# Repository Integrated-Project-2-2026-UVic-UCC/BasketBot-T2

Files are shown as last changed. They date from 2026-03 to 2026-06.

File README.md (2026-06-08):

# 🏀 BasketBot

**Smart Basketball Hoop — Embedded Scoring & Game System**

An ESP32-powered physical basketball scoreboard with motorized height adjustment, multi-player game modes, and a WiFi-hosted mobile web app.

---

## 📋 Overview

BasketBot combines embedded hardware (IR sensors, dual TM1637 displays, NEMA 17 stepper motor, LEDs) with a browser-based remote control interface. The ESP32 serves as both the game controller and a WiFi access point, allowing players to configure games and control the hoop from their phones.

### Key Features
- **4 Game Modes**: 1vs1, Game 21 (1–4 players), Shoot Out, and Free Practice
- **Dual IR Basket Detection**: TSOP58438 sensors detect ball passing through hoop and net with rebound filtering
- **Motorized Height Adjustment**: NEMA 17 stepper with TMC2209 driver
- **Dual Seven-Segment Displays**: TM1637-based time and score readouts
- **Mobile Web App**: Served directly by the ESP32 at `192.168.4.1`
- **Edge-Detected Scoring**: Reliable basket detection with 600 ms cooldown logic
- **Non-Blocking Homing**: Limit-switch-based calibration with automatic backoff

---

## 🎮 Game Modes

| Mode | Players | Description |
|---|---|---|
| **1vs1** | 2 | Classic head-to-head match with timer |
| **Game 21** | 1–4 | First to 21 points wins; supports up to 4 players |
| **Shoot Out** | 1-4 | Timed shooting challenge |
| **Free Practice** | Any | Practice mode with live score tracking |

---

## 🔌 Hardware Architecture

### Microcontroller
- **ESP32 DevKit** (standard development board; IO pin labels map directly to GPIO numbers)

### IR Basket Detection System (New in v2.0)
Dual TSOP58438 sensors with a 38 kHz IR LED emitter for reliable ball detection through the hoop.

| Component | GPIO | Type | Description |
|---|---|---|---|
| Upper Sensor (hoop) | 15 | INPUT | TSOP58438 — detects ball at rim level |
| Lower Sensor (net) | 13 | INPUT | TSOP58438 — detects ball passing through net |
| IR LED Emitter | 12 | PWM OUT | 940 nm IR LED driven at 38 kHz |

**Detection Logic:**
- Ball must break the upper sensor beam first, then the lower sensor within `600 ms`
- Rebounds (upper sensor only) are filtered out with a timeout
- Shots from below the hoop are ignored
- 600 ms cooldown prevents double-counting

### Displays
| Display | Purpose | CLK | DIO |
|---|---|-----|-----|
| TM1637 #1 | Timer | GPIO 26 | GPIO 4 |
| TM1637 #2 | Score | GPIO 14 | GPIO 27 |

### Motor System
| Component | Pin | Notes |
|---|-----|---|
| TMC2209 STEP | GPIO 32 | Step pulses |
| TMC2209 DIR | GPIO 33 | Direction |
| TMC2209 EN | GPIO 25 | Active LOW |
| Limit Switch | GPIO 35 | INPUT_PULLUP |

&gt; **Note:** GPIO 36 was avoided because it lacks internal pull-up on ESP32. GPIO 34/35 are input-only on some boards.

### Game Buttons & LEDs
| Component | GPIO | Mode | Notes |
|---|---|---|---|
| Button Team A | 16 | INPUT_PULLUP | Confirm basket (1vs1) |
| Button Team B | 17 | INPUT_PULLUP | Confirm basket (1vs1) |
| Button Ready | 16 | INPUT_PULLUP | Shared with Team A button |
| Green LED | 21 | OUTPUT | Basket pending / status |
| Blue LED | 19 | OUTPUT | Team A scored |
| Red LED | 18 | OUTPUT | Team B scored |

### Power Supply
- **12V 5A** supply recommended for stability
- **LM2596** buck converter steps 12V → 5V for ESP32 **VIN** pin
- **Never connect 5V to the 3.3V pin**

---

## 📡 Web App

The ESP32 creates a WiFi access point:

- **SSID**: `BasketBot`
- **IP Address**: `192.168.4.1`

### Features
- 4-mode grid layout for game selection
- Drum-style pickers for player count and settings
- Motor setup card with slider and quick-select height buttons
- Mobile-first responsive design

---

## 🗂️ Project Structure

### Naming Convention
All game logic files use mode-specific prefixes to avoid naming conflicts in the global Arduino scope:
- `_g1_` → 1vs1
- `_g21_` → Game 21
- `_gp_` / `_so_` / `_mc_` → Other modes

---

## 🔧 Installation & Setup

### Prerequisites
- Arduino IDE with ESP32 board support
- [TM1637Display](https://github.com/avishorp/TM1637) library by Avishay Orpaz (via Library Manager)

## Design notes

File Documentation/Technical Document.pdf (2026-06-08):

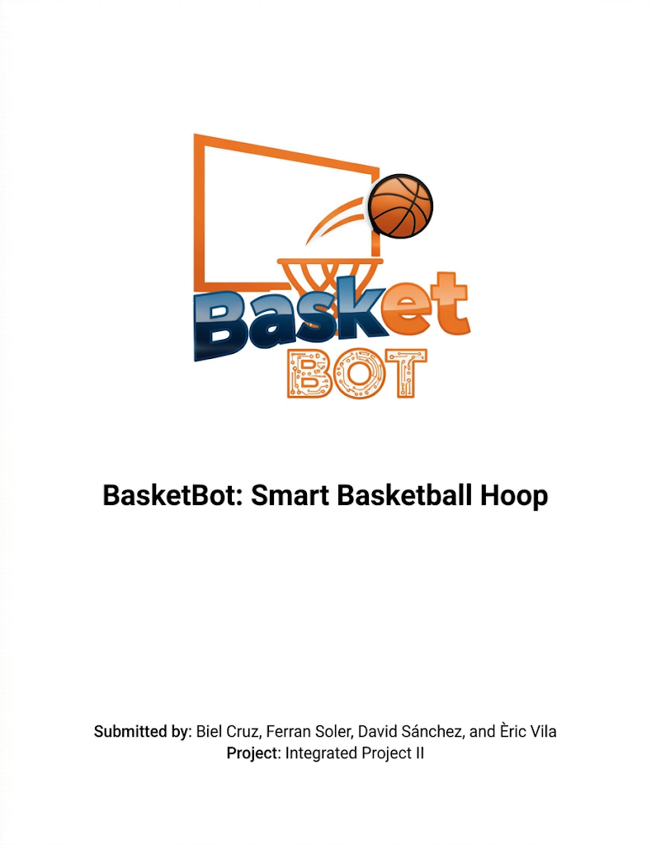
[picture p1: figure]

## Summary

BasketBot is a smart basketball hoop designed to automate score tracking, time control, and turn management in informal games. The primary objective of this mechatronic system is to resolve typical on-court disputes, allowing players to focus exclusively on the game. To achieve this, the project integrates embedded hardware, electronic scoreboards, and a web control interface.

At the hardware level, the hoop features an automated lifting mechanism driven by a NEMA 17 stepper motor with an integrated lead screw, which allows the height of the structure to be adjusted remotely for different types of players. The core of the system is an ESP32 microcontroller that acts as a local Wi-Fi access point and manages peripheral devices. This includes a TMC2209 driver for smooth motor control, a dual infrared sensor (TSOP58438 receivers) for precise and interference-free ball detection, and TM1637 displays alongside LED indicators for instantaneous visual feedback.

The software has been designed to operate asynchronously, ensuring that basket detection and motor movement do not interrupt network communication. Through the locally hosted web application, users can select from four different game modes: Free Practice, The 21, 1 vs 1, and Shootout. During functional testing, communication between the board and the web app demonstrated unnoticeable latency, and the detection accuracy reached 87%, while also overcoming initial mechanical obstacles by stabilizing the lifting structure.

## Table of Contents

## 1. Introduction / State of the art – Benchmarking

Basketball is a global sport, played at both professional and recreational levels. In informal settings—such as schoolyards, parks, or sports centers—matches are typically self-managed by the players themselves. This lack of an external refereeing figure delegates the tasks of tracking the score, managing possession turns, and enforcing the rules of the game to the participants.

The dynamic nature of the game often leads to confusion, involuntary errors, or, occasionally, dishonest behavior that diminishes the sporting experience. The primary motivation of this project is the creation of a smart basketball hoop capable of automating score recording, turn management, and timing.

The idea wasn't born in a lab, but on the court itself. Anyone who has ever played a pickup game with friends knows the drill: you’re winning, the game gets intense, and suddenly, nobody can agree on the score. "Was it 10–8 or 11–9?" That minor doubt sparks arguments and breaks the rhythm of the game.

We are building this project because we want players to forget about the numbers and focus on the ball. We want to use technology to resolve those conflicts and keep the game as clean and fluid as possible. Ultimately, the goal is for the hoop to work for us, not the other way around.

## 2. Objectives

Following the baseline criteria established in the initial project milestones, this system bridges the gap between digital score-tracking web frameworks and automated physical machinery to solve the disputes and tracking errors typical of self-managed, informal basketball games. The main objective of this project is to design, program, and build "BasketBot"—a fully functional, self-contained smart basketball hoop system that integrates embedded hardware and electronic scoreboards with a local WiFi web application to manage games, scoring, timing, and automated mechanical height positioning. Operated by an ESP32 microcontroller acting as a local Access Point, the system coordinates multi-display time and scoreboards alongside a responsive mobile interface to select interactive game modes and dynamically configure match parameters.

To achieve this, the specific objectives focus on delivering robust mechatronic automation, high-integrity electronics, and reliable software logic. The system implements automated mechanical height positioning spanning a linear travel, driven by a NEMA 17 stepper motor and regulated via a physical microswitch homing sequence. On the data layer, precise score registration is guaranteed by utilizing a specialized edge-detection algorithm (HIGH-to-LOW transition logic) with strict software cooldown timers to eliminate multi-count sensor ghosting. Power distribution is optimized using an LM2596 DC-DC buck converter to step down a stable 12V main source into a clean 5V line connected directly to the ESP32 VIN pin, protecting sensitive digital control logic from inductive motor loads. Finally, the entire modular software architecture and interactive game routines are structured, version-controlled, and documented collaboratively using a Git repository on GitHub.

## 3. Development of the project

In order to achieve the final prototype and fulfill all the proposed objectives, it is essential to divide the project development into several core areas. On one hand, we find the tasks focused on mechanical design, such as numerical calculations, 3D modeling, and lifting mechanisms. On the other hand, the project focuses on the electronic and control systems, which encompass the electrical schematics, sensor integration, and mobile app connectivity. Finally, all aspects regarding software programming and system firmware are thoroughly developed.

## 3.1. Analysis of the problem and possible solutions

To achieve a variable-height basketball hoop that syncs data with a mobile application, several architectural solutions were considered:

- Mechanical Lifting Mechanism: We evaluated several options for the basket-lifting system, including a gear-based mechanism. But in the end, for the sake of simplicity and control, we opted for a motorized lever mechanism driven by a stepper motor.

In this system, the motor drives a rigid rod connected directly to the backboard mount. This creates an inverted lever system: when the motor pushes the rod upward, the basketball hoop moves downward, and vice versa.

- Electronic Score Tracking: We analyzed using ultrasonic sensors, infrared (IR) break-beam sensors, or a camera system to detect when a basket is scored. IR/Ultrasonic sensors were selected due to their reliability and low computational requirements.
- Connectivity: Wi-Fi in Access Point (AP) mode was chosen to facilitate direct, low-latency communication with the web application hosted on the ESP32. By establishing its own local network, the microcontroller allows users to access the control interface directly via a web browser using its local IP address, completely eliminating the need for an external network or internet connection.

## 3.2. Description of the design

The BasketBot is a mechatronic system defined by the following core characteristics:

- Dimensions & Weight: 65 cm long by 35 cm wide. Weighing 6 kg.
- Degrees of Freedom: One vertical degree of freedom (translation for height adjustment).
- Power Supply: The system is powered from a single external 12V DC power supply. A DC-DC step-down regulator (LM2596) converts this voltage to 5V, which powers the two TM1637 displays (scoreboard and timer). The remaining components — ESP32, TSOP4838, ultra sonics sensor, LEDs, push buttons, and limit switches — operate at 3.3V, supplied by the ESP32’s internal regulator. The TMC2209 driver and the NEMA 17 motor are powered directly from the 12V input. The 330Ω and 220Ω resistors limit the current of the LEDs, protecting them.
- Microcontroller & Language: The system is controlled by an ESP32 microcontroller, programmed in Arduino using the Arduino IDE.

## 3.2.1. Mechanical design

The mechanical design of the system was conceived to fulfil two main objectives: to provide a rigid and robust structure capable of withstanding impacts and movements, and to implement a reliable vertical lifting mechanism. The design is clearly divided into fixed structural components and mobile structural components.

Fixed Structural Components

Rim:
It is a simple design, engineered with enough strength to withstand ball impacts corresponding to its size, yet retaining the flexibility that characterizes a basketball hoop rim. It also features four holes on the back section to ensure it can be easily and securely attached to the backboard.

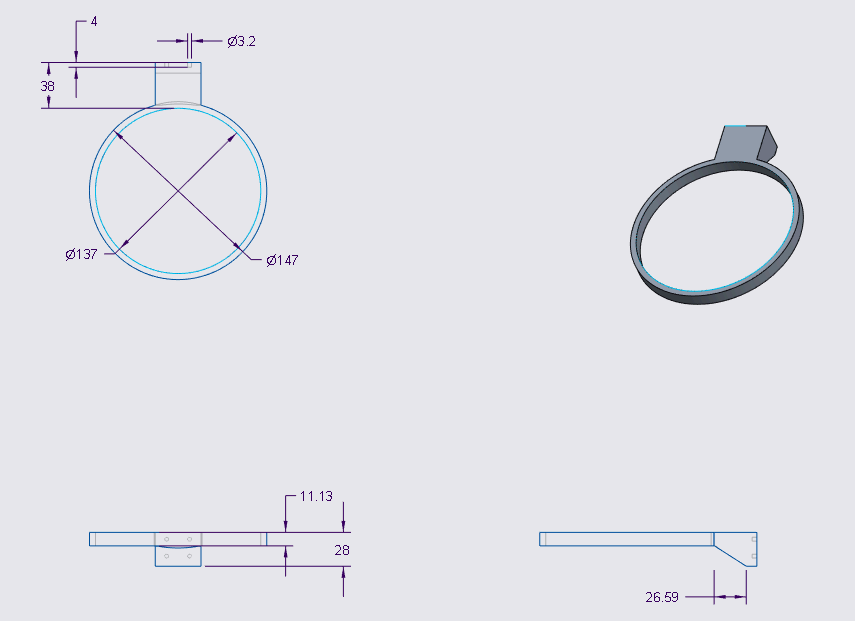
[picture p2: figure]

Figure 1 Rim

Main Structure:
The main body of the structure is constructed from wood, which provides a solid and stable frame for the system. To achieve the exact required height, a custom plastic base was integrated at the bottom for precise adjustment. Additionally, the assembly includes a counterweight system designed to balance the structure's weight, ensuring that the basket remains stable and does not tilt or fall forward during operation.

Mobile Structural Components

Support Arms and Sliding Carriages:
The mechanism that moves and supports the board operates like a dual-arm parallel system. It consists of two pairs of parts stacked one above the other. This gives the board four points of support at all times, preventing it from swaying or tilting forward as it rises and falls.

On one side, we have the support arms, which are two identical pieces attached to the back of the panel. On the other side, these arms connect to the following square pieces. These are hollow pieces that are fixed to the basket body. One of them has a pin or joint on the back connected directly to the driveshaft. In this way, it receives the force from the engine directly and pulls the entire assembly.

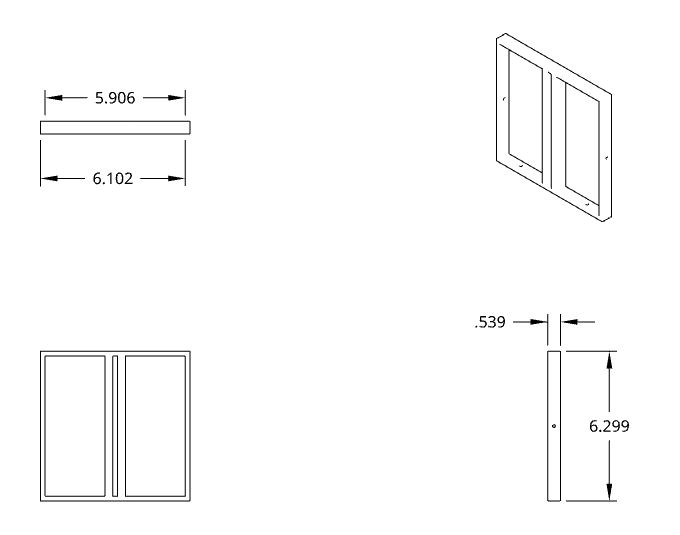
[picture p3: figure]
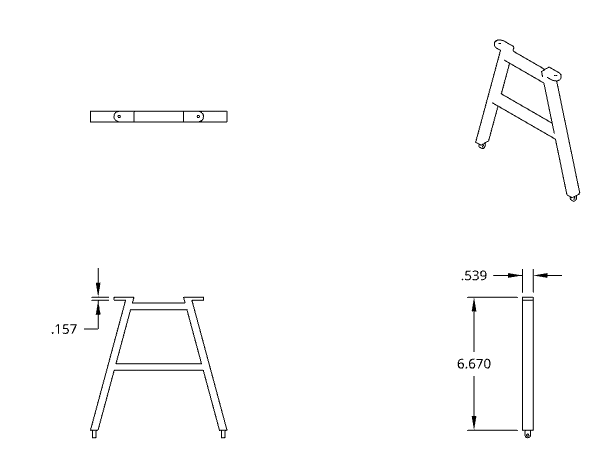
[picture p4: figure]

Figure 2 Support Arms and Sliding Carriages

Brackets / Connectors:
This small component was designed to enable the articulated connection between the backboard and the supports of the mechanism that drives the movement. It has a solid base with two holes for a secure and sturdy collar, and a double upper support with an axle that allows the lifting system to rotate and articulate smoothly and stably.

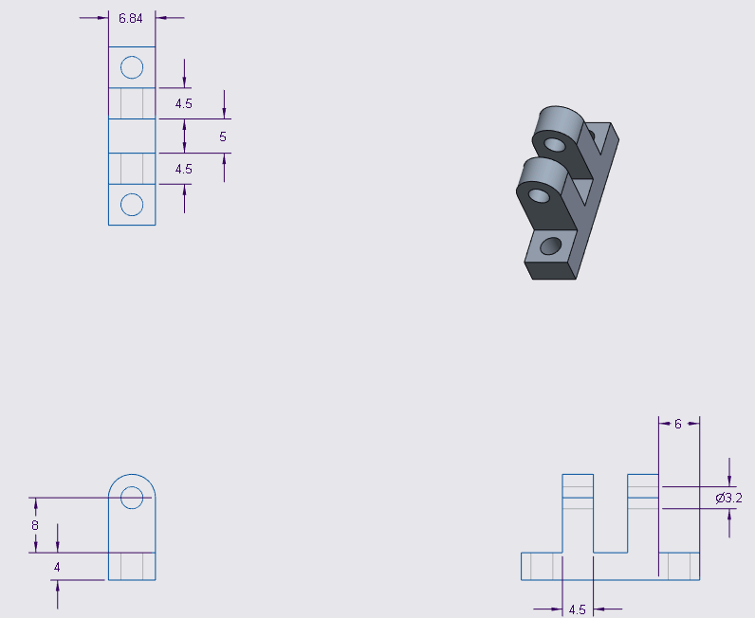
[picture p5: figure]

Figure 3 Brackets

Transmission Rod (Linkage / Connecting Rod):
It is the direct transmission between the stepper motor and the basket's moving structure. Its function is to convert the motor's motion into a vertical linear force that pushes the board support up or down, thereby generating the basket's regulated displacement.

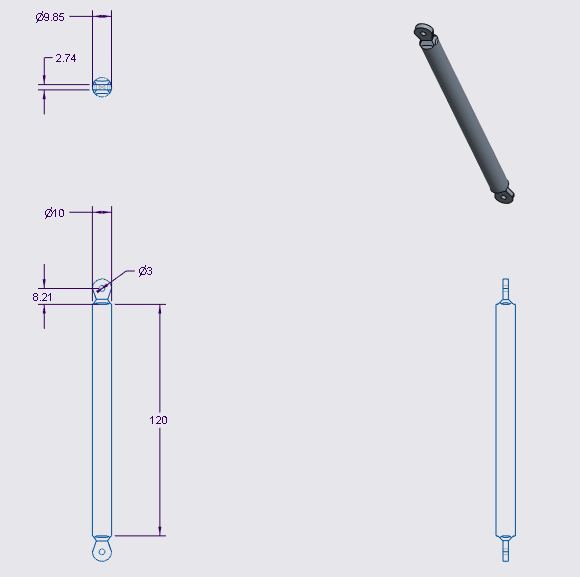
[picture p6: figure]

Figure 4 Transmission Rod

## 3.2.2. Electrical design

Connection Mapping and Pin Assignment

For the final assembly, we organized the ESP32 connections in a much more efficient manner (Table 1). Compared to the first version of the prototype, we had to reassign the pins of some components (such as the displays).

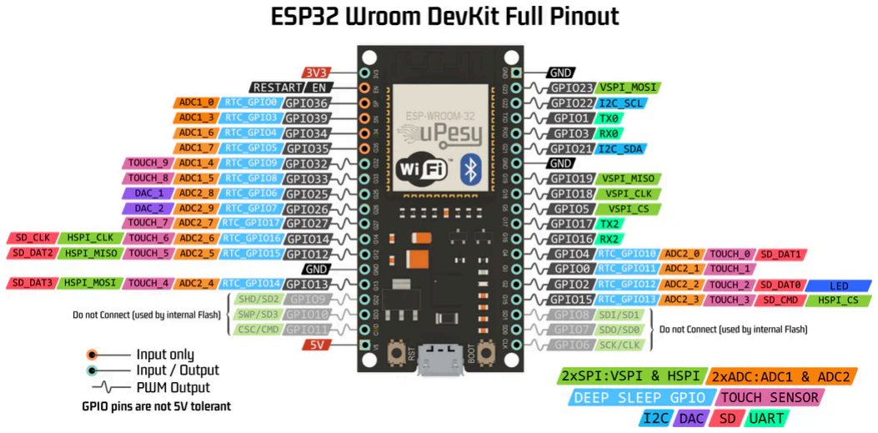
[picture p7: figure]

Figure 5 ESP32 Pinout

IR Basket Sensors
- TOP Sensor (TSOP58438): GPIO 15.
- BOTTOM Sensor (TSOP58438): GPIO 13.
- IR Emitter LED (38kHz): GPIO 12.

Displays (TM1637)
- Display Timer CLK: GPIO 26.
- Display Timer DIO: GPIO 4.
- Display Score CLK: GPIO 14.
- Display Score DIO: GPIO 27.

Basket Motor (NEMA 17)
- STEP: GPIO 32.
- DIR: GPIO 33.
- ENABLE: GPIO 25.
- Limit Switch: GPIO 35

Buttons and LEDs (Games)
- Team A Button / Ready Button: GPIO 16.
- Team B Button: GPIO 17.
- Green LED (Pending basket / Indicator): GPIO 21.
- Blue LED (Team A scored): GPIO 19.
- Red LED (Team B scored): GPIO 18.

Control Architecture (The “Brain”)

The core of the BasketBot electrical subsystem is governed by a central control unit based on the ESP32 Wroom DevKit microcontroller. This device acts as the "brain" of the smart basketball hoop, serving as the central node where data acquisition lines (sensors), game logic algorithms, mechanical actuation systems (motor), and the user interface (LEDs and web application) converge.

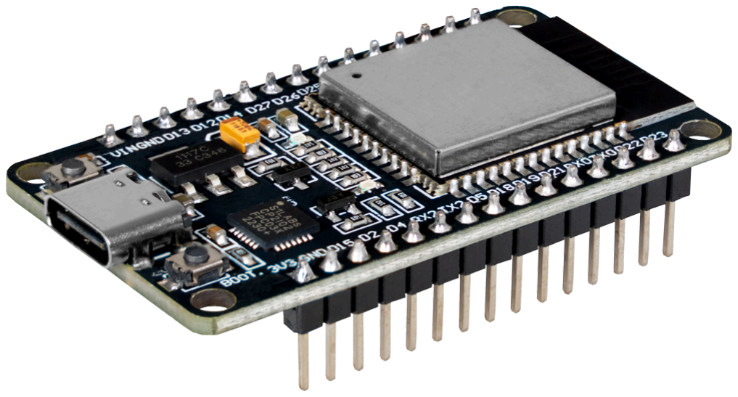
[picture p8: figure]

Figure 6 ESP32

The selection of the ESP32 instead of other market alternatives (such as 8-bit Arduino platforms) is based on the project's technical and connectivity requirements:

- Integrated Connectivity: The ESP32 incorporates certified hardware modules for Wi-Fi and Bluetooth (BR/EDR and BLE). This feature is essential to achieve the goal of connecting the basketball hoop to a web-based mobile application, eliminating the need for external communication chips that would increase both the cost and complexity of the electrical design.
- High Peripheral Density and PWM Channels: The chip provides a wide array of addressable GPIO pins, including internal timers, pulse generators (essential for the stepper motor driver), and serial communication ports.

Motor NEMA 17 stepper motor with integrated T8 lead screw

The selected motor is a NEMA 17 stepper motor with a 310 mm T8 lead screw integrated directly into the shaft. Its main electrical and mechanical characteristics are as follows:

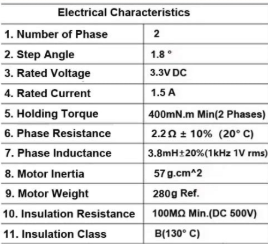
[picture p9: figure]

Table 1 Electrical Characteristics

In order to meet the functional requirements, several technological alternatives were evaluated before making the final decision. The main selection criteria were: the ability to perform open-loop position control, meaning that it does not require an external encoder to determine its position; compatibility with the ESP32; and a cost that fits within the project's budget.

Sufficient torque to move the basket structure was also a critical factor. According to the manufacturer's datasheet, the chosen stepper motor is capable of lifting a maximum load of 12 kg. During the design phase, the total weight of our basket prototype was calculated to be approximately 6 kg. This means the motor offers twice the capacity required by the system, providing an ample safety margin to handle the structure effortlessly, prevent any loss of steps, and overcome unexpected friction during movement.

The main objective of this subsystem is to enable the motorized adjustment of the basketball hoop's height, allowing the BasketBot system to adapt to different types of players—whether children, teenagers, or adults—without requiring manual intervention.

The height adjustment is carried out through a lead screw mechanism driven by a stepper motor, which converts the motor's rotational motion into a vertical linear displacement of the structure supporting the basketball hoop.

The control of this subsystem is integrated directly with the project's mobile application. Through the app, the user can select the desired hoop height before starting a game or adjust it in real time using the up and down buttons. This command is transmitted via Wi-Fi to the ESP32, which is responsible for generating the control signals required to drive the motor in the appropriate direction and reach the target position.

In addition, the subsystem incorporates two limit switches that physically define the maximum travel range of the mechanism, ensuring that the motor does not exceed the structural limits of the minimum and maximum permitted heights. This provides both system safety and protection for the mechanical components.

Driver: TMC2209

To control the NEMA 17 from the ESP32, a TMC2209 driver is used. This next-generation integrated circuit is specifically designed for bipolar stepper motors. It represents a significant improvement over more basic drivers such as the A4988, particularly in terms of quieter operation, smoother motion, and advanced functionality.

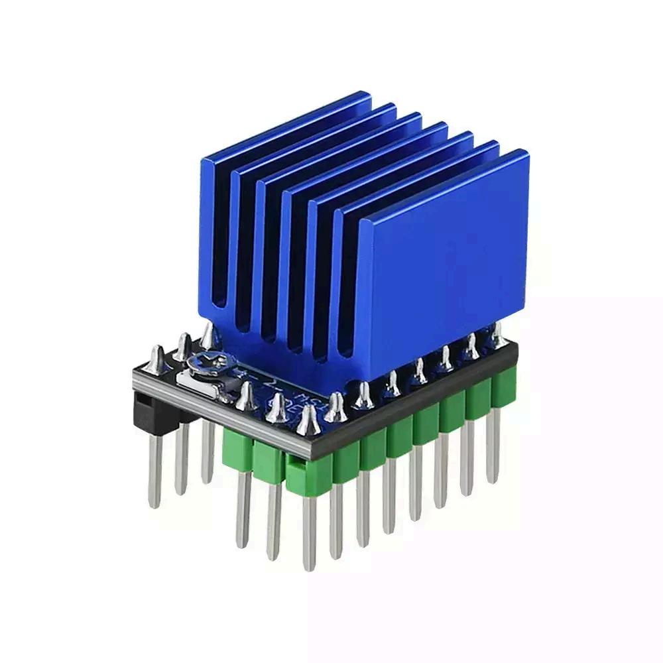
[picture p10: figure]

Figure 7 Driver TMC2209

Basic Operation of the Motor and Driver

The NEMA 17 is a bipolar stepper motor with two independent coils (Phase A and Phase B). The TMC2209 driver energizes these coils in a specific sequence, generating a rotating magnetic field that drives the rotor in precise, discrete steps with virtually silent operation.

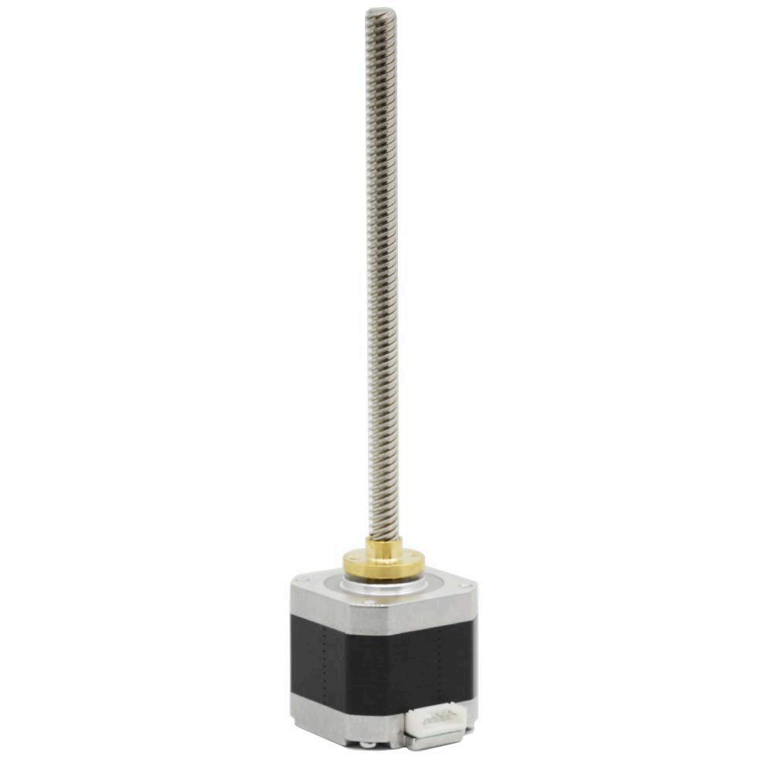
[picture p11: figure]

Figure 8 Nema 17

Each time the ESP32 sends a rising edge to GPIO 32 (STEP pin), the TMC2209 advances the motor exactly 1.8°. The direction of rotation is determined by the logic level of GPIO 33 (DIR pin).

The TMC2209 driver internally manages the coil energizing sequence and current control, so the ESP32 only needs to generate two simple digital signals, without any additional motor control computations.

Digital Scoreboards (TM1637 Displays)

The BasketBot uses two 4-digit, 7-segment display modules controlled by the TM1637 chip (one for time and another for score).

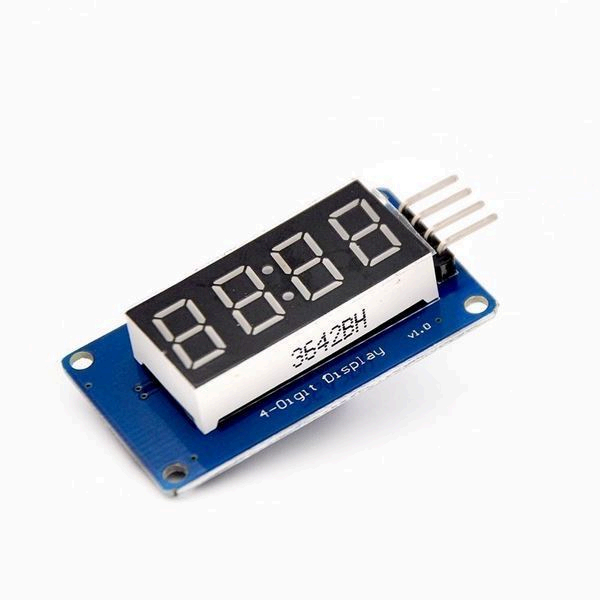
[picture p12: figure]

Figure 9 TM1637

Its selection is justified by two key electrical reasons:

- Massive pin saving: Controlling a standard 4-digit display would require 12 wires connected to the ESP32. With two displays, this would amount to 24 GPIO pins, leaving insufficient connections for the rest of the system components. The TM1637 chip acts as an intelligent intermediary and only requires 2 data wires (CLK and DIO) per display, greatly saving space on the board.
- Multiplexing (optical illusion): The TM1637 does not power all digits simultaneously, as this would consume too much energy. Instead, it turns each digit on and off sequentially at an extremely high frequency (in the kHz range). Because this switching happens so quickly, the human eye does not perceive the flickering and instead sees all four digits lit at the same time, without overloading the system.

Display Connections

Since we are using two independent displays, each one requires a two-wire connection to receive data from the ESP32.

- Time Display (Timer): The clock line (CLK) is connected to GPIO 26, and the data to GPIO 4.
- Score Display: It remains connected as before, with CLK on GPIO 14 and DIO on GPIO 27.

Feedback Indicators (RGB / Simple LEDs)

As a complement to the numeric score displays, a lighting system based on three visual indicators has been designed. These serve as a visual communication interface (Green LED, Blue LED, and Red LED).

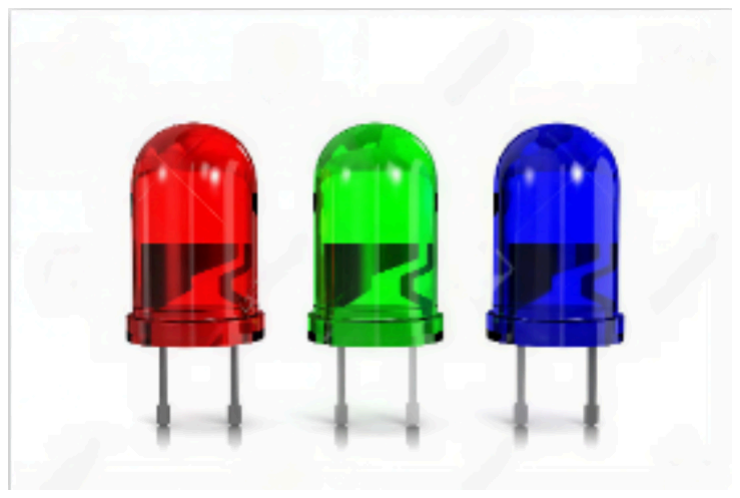
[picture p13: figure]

Figure 10 LED

Their electrical configuration and activation logic correspond to the following stages of game interaction:

Green LED: At the exact moment the ball passes through the hoop successfully, the ESP32 toggles the pin connected to this LED, producing an instant green light that confirms a valid basket.

Team Assignment LEDs (Blue and Red): These are used to identify which of the two competing teams has scored points on the scoreboard. To prevent incorrect assignments, the software requires a prior validation step:

- Physical Interface: The system includes two manual push buttons (one for the blue team and one for the red team). Electrically, these buttons are configured as digital inputs with pull-up resistors to ensure clean and stable readings.
- Digital Interface: Alternatively, the assignment can be performed remotely through the web mobile application using the same control protocol.

LEDs: Each color is assigned its own digital output channel on the ESP32. The Green LED is connected to GPIO 21; the Blue LED (which confirms a point for Team A) is connected to GPIO 19; and the Red LED (which confirms a point for Team B) is connected to GPIO 18. Each wire includes a small series resistor to prevent excessive current from reaching the LED, which could otherwise damage either the LED itself or the microcontroller pin.

Buttons (Physical Push Buttons): Physically, we have two buttons, which helps us save components and board space. They work as follows:

- 1vs1 Game mode: The Team A button is connected to GPIO 16 and the Team B button to GPIO 17. They are used to confirm which team made the basket that has just been scored.
- Mode 21, Shootout and Free modes: Not used.

Interconnection and Integration with Sensors

The system responsible for automatically and reliably detecting baskets uses a dual infrared (IR) optical barrier. The TSOP58438 receiver was selected to avoid false positives caused by sunlight or artificial lighting, as it completely ignores surrounding ambient light and only responds to infrared bursts modulated precisely at 38 kHz.

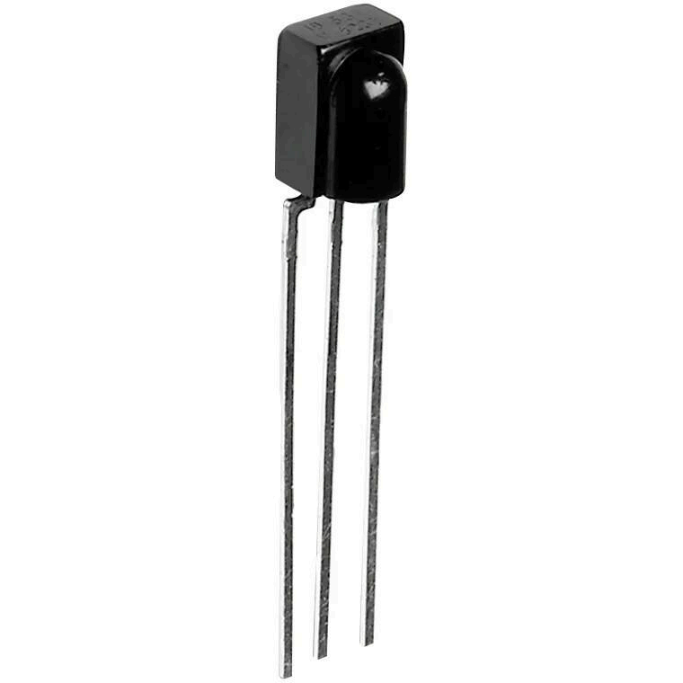
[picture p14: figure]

Figure 11 TSOP58438

To ensure a stable electrical integration free from false detections, the pin-to-pin connection between the receiver and the control architecture has been designed as follows:

- IR LED: Connected to GPIO 12; it is the LED that emits the infrared light.
- TOP Sensor: Connected to GPIO 15. It acts as an input to notify the program at the exact moment the ball begins to enter the hoop.
- BOTTOM Sensor: Connected to GPIO 13. It acts as a second input to confirm that the ball has fully passed through and fallen completely.

## 3.2.3. Control and software

Game and Team Validation Flow Logic

To prevent errors or false scoring, a state machine has been implemented under a strict dual-condition flow:

1. Detection Phase (Physical): When the ball passes through the hoop, the IR sensors are activated. The ESP32 immediately turns on the Green LED to confirm that a valid basket has been physically detected. At this stage, no points are added to the scoreboard yet.
2. Validation Phase (Human): The system then waits for a few seconds. In order for the point to be registered, the scoring team must be indicated. This is done using the manual push buttons (one for the Blue team and one for the Red team) or directly through the web application.
3. Update Phase: Once the team signal is received (via button or Wi-Fi), the ESP32 turns off the Green LED, turns on the corresponding team LED (Blue or Red) as a visual confirmation, and automatically updates the Score Display (TM1637), adding the points to the appropriate team’s score.

Game Modes

Free (Free Practice)

This module is a free training mode with no time or scoring limits, controlled by a single scoreboard.

Objective and operation:

- Scoring: Each valid basket detected by the sensor adds +2 points.
- Visual effect: When a basket is scored, a LED (GPIO 21) lights up for 200 ms. The function turns it off in the background without using blocking code.

Web Interaction

- Manual control: The user can add +2 points or use the “Undo” button to subtract 2 points in case of an error.
- Safety: The code uses max(0, _gl_puntos - 2) to prevent the score from going below zero.
- Synchronization: Data is sent in JSON format to update the mobile screen in real time.

Win Condition

There is no win condition. The game continues accumulating points until the user presses reset or stops it from the web interface.

The 21

This mode allows 1 to 4 players to play in an automated way. It controls an indicator LED to mark the shooting time and communicates with the web interface.

Objective and scoring

The objective is to reach exactly 21 points. The game operates using a turn-based system based on a time window:

- Normal Shot: If the player scores, they earn +2 points and receive an extra “Free Throw” attempt. If they miss or time runs out, the turn passes to the next player.
- Free Throw: If the player scores, they earn +1 point and can continue taking free throws. If they miss, they lose their turn.

If the ball hits the rim and bounces out, the system immediately detects it as a miss and switches turns without waiting for the time to expire.

Win condition and penalty

- Victory: The first player to reach exactly 21 points wins.
- Penalty: If a player exceeds 21 points (for example, having 20 points and scoring 2), their score is automatically reduced to 11 points and they immediately lose their turn.

The 1 vs 1

This module manages a real-time match between two teams sharing the same hoop, using physical buttons to assign points. It uses GPIO 16 (Team A), GPIO 17 (Team B), and three control LEDs: Green (GPIO 21), Blue (GPIO 19), and Red (GPIO 18).

Objective and operation

- Objective: To score more points than the opponent before the game time runs out.
- Validation window: When a basket is scored, the Green LED turns on and a waiting state is activated. The first team to press their button within the time limit earns +2 points. If no button is pressed, the basket is cancelled.

End of match

When the timer reaches zero, the function turns off all LEDs, locks the game, determines the winner (or a draw), and sends the final result to the web interface.

Shootout

This module manages a timed competitive turn-based mode (1 to 4 players). It uses a “Ready” button (GPIO 16) and an indicator LED (GPIO 21).

Objective and operation

- Objective: Score as many baskets as possible within a time limit (e.g., 30 seconds). Each successful shot adds +1 point.
- Asynchronous timing window: If the game is paused from the web interface, the code calculates the time spent paused and compensates for it by adding it back to the board’s timer, ensuring the player does not lose any seconds.

Win condition and tiebreaker

- Victory: The player with the highest score wins.
- Automatic tiebreaker: If there is a tie for first place, an exclusive group is created where only the tied players compete. Their scores are reset to 0 for an additional round. This process is repeated until a single winner is determined.

Motor Control

To ensure everything works correctly and without freezing, the programming has been structured as a state machine that runs asynchronously (non-blocking). This is essential so that the ESP32 doesn't get "frozen" while the motor is moving; it allows the microcontroller to continue performing other tasks simultaneously, such as updating the scoreboard or managing communications. Instead of making long, single-shot movements, the code uses a function called motor_tick() that runs continuously in the program's main loop. Every time this function is called, the ESP32 checks the current state of the system and, if necessary, moves the motor a single step before continuing with the rest of the code.

The main states managing this logic are the following:

- Idle (MC_IDLE): The motor has reached its destination and remains stopped, waiting for a new height command.
- Homing (MC_HOMING_DOWN and MC_HOMING_UP): These are the two phases to find the zero point using the limit switch. First, the motor moves down until it triggers the limit switch, and then it moves up a few steps to release it, establishing this position as the reference origin.
- Moving (MC_MOVING): The active state where the motor moves (upwards or downwards) to the height in centimeters requested by the user. To do this, the system converts the desired height into a number of motor steps by applying a conversion factor of 2,000 steps per centimeter, derived from the pitch of the T8 lead screw and the motor's step angle.
- Error (MC_ERROR): The failure state the system enters when a critical anomaly is detected. In this case, the motor is immediately disabled to protect the mechanical structure.

Finally, essential safety measures have been included within the code itself to protect the mechanical structure. On one hand, if the motor moves down during the initial homing phase without finding the limit switch, the system assumes a fault has occurred, stops immediately, and enters the MC_ERROR state, disconnecting the motor to prevent any damage. On the other hand, if the motor is moving normally and unexpectedly hits the limit switch, the software instantly cancels the movement and resets the position to zero to avoid mechanical collisions.

Hoop Sensors

Phase 1: Testing and calibration program

Before integrating the sensors with the web interface or the motors, we created a simple standalone program solely to test how the IR receivers responded. This code continuously monitored the pins and displayed a message on the computer screen every time the ball passed through. Thanks to this test program, we were able to calibrate the infrared light distance and verify that the 38 kHz modulation of the emitting LED worked even under ambient light conditions.

Phase 2: Final Code

The final code was designed around three technical pillars:

Asynchronous operation: Instead of using typical delays, the code calculates real elapsed time using the ESP32’s internal clock. This is essential so the sensor can monitor the ball in the background while, at the same time, the hoop motor is moving or the user is interacting with the web application.

IR burst logic: The LED is not kept continuously on. The program activates the emitter in bursts, turns the LED off, and at that precise moment performs the digital reading. It then leaves a recovery margin before the next cycle.

State machine flow control: The program manages the ball trajectory sequentially to avoid scoring errors:

- Waiting: It waits for the upper sensor to be triggered. When this happens, it records the time and opens a safety window.
- Checking: If the lower sensor is triggered within 600 ms, the basket is validated. If the time limit is exceeded, the code assumes the ball has bounced out and returns to the initial state without scoring.
- Anti-bounce: Once a basket is detected, the system locks for 1 second. During this period, sensors are ignored to prevent rim vibrations from generating extra points.

### Displays

Score

Depending on the game mode, the score display behaves differently:

- 1vs1 mode: The display is split into two halves of 2 digits each. The left side shows Team A’s score and the right side shows Team B’s score (up to 99). The middle segments are disabled to simulate two independent scoreboards.
- 21, Shootout and Free modes: The display acts as a single 4-digit counter (0000–9999), showing the total score or the score of the active player’s turn.

Whenever a match is paused, has ended, or the system is in standby, the display shows four fast dashes (----) to visually indicate that the counter is inactive.

Timer

The same applies to the timer display:

- 1vs1 mode: Displays the total game time in minutes and seconds (MM:SS). To achieve this, the code calculates the quotient and remainder of the remaining time.
- Shootout and 21 modes: Since these are fast countdown-based shooting modes, the display is configured in integer seconds (SS), using leading zero padding for proper visual alignment.
- Free mode: Since this mode has no time restriction, the timer is disabled.
- Inactive state: As with the scoring module, if the game is paused, finished, or in standby, it shows four fast dashes (----) as a visual indicator that the game is frozen.

Web Application and Wi-Fi Communication
This subsystem interconnects the mobile web application with the ESP32 control logic through an asynchronous architecture, ensuring an instantaneous response (low latency) and completely independent operation from the internet or external network infrastructures.
- Access Point Mode: The ESP32 generates its own local Wi-Fi network with a dedicated SSID. Users connect directly to this network and access the control interface by entering the microcontroller's local IP address into any mobile web browser, eliminating the need for external routers or servers.
- Control Interface & Features: The web application features a responsive design optimized for smartphones. Through this graphical interface, users can select from the four available game modes (Free Practice, The 21, 1 vs 1, and Shootout), adjust the hoop's mechanical height in real-time, and manage the scoreboard with specialized correction features such as the Undo button.
- Asynchronous Data Flow (JSON): Data exchange between the control board and the mobile interface is handled via structured JSON payloads. By implementing non-blocking asynchronous programming based on the ESP32's internal clock (avoiding blocking code like delay()), the mobile screen updates instantaneously whenever a basket is registered or a timer changes, without ever interrupting background sensor polling or stepper motor movements.

## 3.3. Functional testing of the prototype

To validate the performance of the BasketBot, a series of experimental tests were conducted:

1. Height Adjustment Test: Initially, although the motor had sufficient torque according to its datasheet and responded perfectly to commands, the mechanism failed to lift. We discovered the issue was a lack of structural stability: the weight of the hoop tilted the motor's support shaft, preventing movement since the system requires perfect vertical alignment to avoid jamming. To solve this, we added a counterweight to balance the load and reinforcing bars to keep the structure completely upright. Thanks to these modifications, the lifting mechanism now functions perfectly, smoothly, and stably.
2. Score Detection Accuracy: 100 shots were taken to evaluate the detection system's accuracy, obtaining 87 correct detections (87%). During testing, it was found that the upper sensor required readjustment to improve detection, so it was temporarily disabled until the final version.

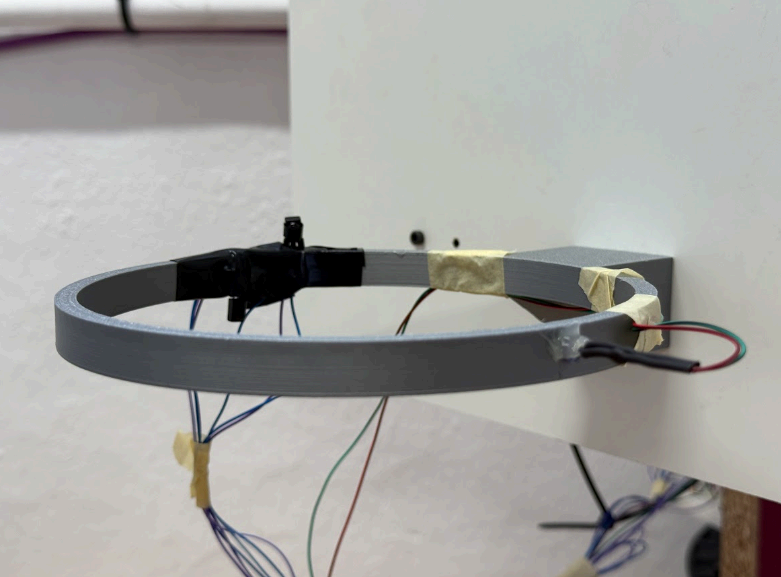
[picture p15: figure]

Figure 12 Score Detection

### 3. App Synchronization and Latency: The synchronization between the mobile

application and the physical system was highly successful and operated without any major complications. Across all available features and game modes, the application detected and updated the scoreboard with a latency that was practically unnoticeable to the user.

Furthermore, regarding the response time when selecting different options or changing settings within the app, the system delivered excellent results, executing commands almost instantaneously. Overall, the data transmission proved to be highly reliable, stable, and free of any unexpected disconnections.

### 4. Limitations Identified: Throughout the development of the project, we identified two

primary limitations that affected the system's initial performance:

- Lifting Mechanism: As previously mentioned, a lack of structural stability and a slight tilting of the main support shaft initially prevented the motor from moving, an issue we successfully resolved by adding a counterweight and reinforcing bars.
- Sensor System: We encountered several issues regarding the synchronization of the detection sensors. We could not get them to function simultaneously; whenever one sensor was connected, the other stopped working. Troubleshooting this specific conflict and fixing the connection errors required a significant amount of time and testing.

## 4. Cost of the project

This section outlines the total economic investment required for the development of the BasketBot prototype. The budget is divided into human resource expenses (man-hours) and the physical material component procurement.

## 4.1. Engineering Man-Hours

The project development was collaboratively executed over a 15-week timeline by the four team members. A standard engineering labor rate of 20.00 €/hour has been applied to quantify development costs. The labor distribution across the mechatronic engineering areas is detailed in the table below:

Team Member | Project Role | Total Hours | Labor Cost (€)
Èric Vila | Project Manager | 106 | 2120 €
Ferran Soler | Mechanical Leader | 100 | 2000 €
David Sánchez | Electronics Leader | 99 | 1980 €
Biel Cruz | Software Leader | 75 | 1500 €
| | Total: | 7600 €

Table 2 Man-Hours

## 4.2. Material Budget

The physical component expenses correspond directly to the preliminary shopping list managed for prototyping. The prototype remains well within the university-established 300.00 € threshold:

Material | Quantity | Unit Price (€) | Total Cost (€)
Motor NEMA 17 Stepper | 1 | 32.22 | 32.22
Driver TMC2209 | 1 | 10.32 | 10.32
ESP32 | 1 | 6.87 | 6.87
TSOP4838 | 1 | 11.04 | 11.04
TM1637 | 2 | 5.6 | 11.2
Push button | 2 | 0.3 | 0.6
Limit sensor switch | 1 | 1 | 1
Rsistor 100 Ω | 1 | 1 | 1
Rsistor 330 Ω | 3 | 1 | 3
LED IR de 940 nm | 1 | 5.99 | 5.99
Blue Led | 1 | 0.3 | 0.3
Green Led | 1 | 0.3 | 0.3
Red Led | 1 | 0.3 | 0.3
Protoboard | 1 | 2 | 2
| | Total: | 86.14 €

Table 3 Material Budget

## 4.3. Total Project Budget

The total financial execution sum of the BasketBot mechatronic development combines both direct material acquisition and calculated engineering engineering assets:

Total Project Cost = 7600 + 86.14 = 7686.14€

The resulting financial distribution demonstrates that while the physical components and prototyping materials were kept well under the university-established limits to ensure affordability, the true value of the mechatronic asset lies in the engineering man-hours dedicated to system integration, software namespacing architecture, and structural hardware optimization.

## 5. Conclusions

BasketBot was born from a situation we've all experienced at some point: you're playing, the game heats up, and suddenly nobody agrees on the score. That classic argument of "was it 10 or 11?" is exactly the problem we set out to solve. And we believe we've succeeded.

Throughout this semester, we have designed, programmed, and built a complete mechatronic system that automates the scoreboard, manages turns, and controls game time, all integrated into a web application accessible from a smartphone without the need for an external internet connection. The ESP32 has proven to be the ideal heart of the system, simultaneously coordinating basket detection, motor control, scoreboard updates, and Wi-Fi communication without any of these tasks interfering with one another. In all the tests conducted, the application's response has been practically instantaneous, and data transmission has remained stable and reliable across all game modes.

The lifting mechanism, one of the project's most demanding mechanical challenges, ultimately functioned smoothly and stably after we resolved a structural alignment issue that initially prevented movement.

However, detection accuracy reached 87% over 100 real shots, and the upper sensor had to be temporarily disabled due to a synchronization conflict between the two infrared receivers. These are real limitations that we aren't hiding; rather, they clearly outline the path for future improvements: resolving the sensor interference to exceed 95% accuracy, permanently soldering the connections on the protoboard to improve system robustness, and adding closed-loop control to the lifting system.

Ultimately, BasketBot is a system designed for everyone and built for fun. It lets the hoop do the work so players can focus on what really matters: the game.

## 6. Bibliography

Hardware Datasheets & Technical Documentation

[1] Espressif Systems, ESP32-WROOM-32 Datasheet, Espressif Systems Hardware Documentation. https://www.espressif.com/en/support/documents/technical-documents
[2] TMC2209 Datasheet: Ultra-silent driver for two-phase stepper motors, https://www.alldatasheet.com/view.jsp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 (https://www.alldatasheet.com/view.jsp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)
[3] Titan Micro Electronics, TM1637 LED Drive Control Special Circuit Datasheet.https://robotlandia.es/display/848-pantalla-de-4-digitos-y-7-segmentos-con-driver-tm1637.html (https://robotlandia.es/display/848-pantalla-de-4-digitos-y-7-segmentos-con-driver-tm1637.html)
[4] Vishay Semiconductors, TSOP4838 / TSOP58438 IR Receiver Modules for Remote Control Systems, Vishay Intertechnology. https://www.vishay.com/
[5] Texas Instruments, LM2596 SIMPLE SWITCHER Power Converter 150-kHz 3-A Step-Down Voltage Regulator, Texas Instruments Technical Documentation. https://www.ti.com/product/LM2596
[6] NEMA 17 Stepper Motor: Manufacturer's specifications for the model with the integrated T8 lead screw

Software & Development Tools

[7] Arduino, Arduino IDE Documentation and Language Reference.
[8] GitHub Docs, Git and GitHub Documentation, GitHub. https://github.com/Integrated-Project-2-2026-UVic-UCC/BasketBot-T2

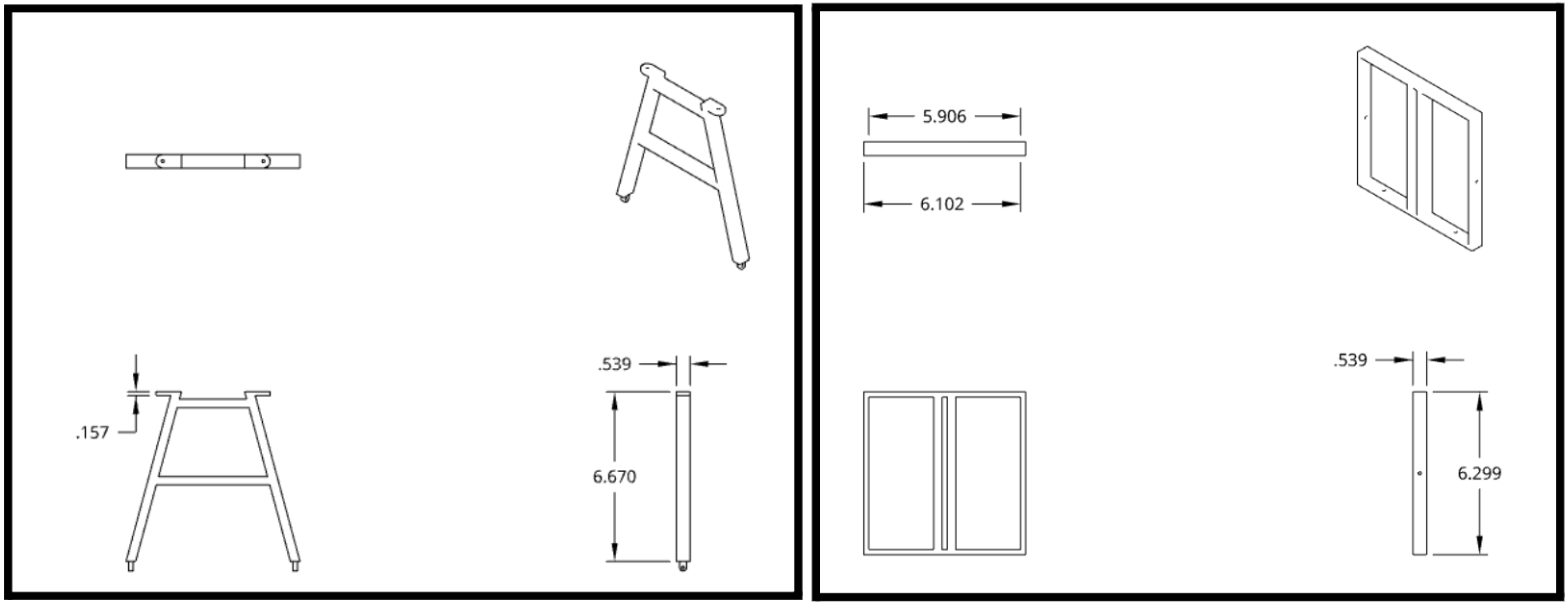
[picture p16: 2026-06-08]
Design/Suport Arms and Sliding Carriages.png

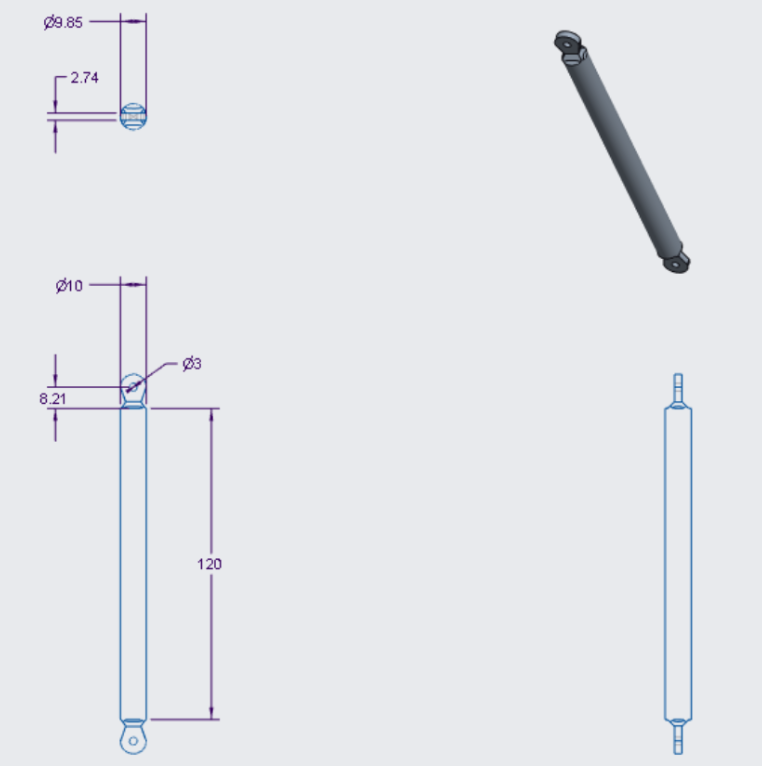
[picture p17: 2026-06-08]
Design/Transmission Rod.png

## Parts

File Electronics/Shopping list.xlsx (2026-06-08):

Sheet: Project Specifications
TECHNICAL SPECIFICATIONS
Customer Company | Universitat de Vic - Universitat Central de Catalunya
Engineering Company | BasketBot
Revision 1 | Date: 25/02/2026
List the main characteristics of the desired device
Item number | Description
1 | Design a basketball hoop with adjustable height for children and adults
2 | Implement an electronic scoreboard and timeboard.
3 | Detect if a ball goes in or not and to prevent the ball from going in underneath and to verify that the ball has actually gone in.
4 | Use an ultrasonic sensor to validate the player’s position during specific game modes.
5 | Develop a mobile web application to select game modes, display score, player turns, remaining shooting time and configure hoop height and game parameters
Mechanical part
Dimensions (volume) | Support dimensions: 150 mm x 200 mm x 400 mm Backboard dimensions: 458 × 267 mm Hoop dimensions: Ø 114 mm
Weight | Hoop 300g (what the motor needs to move) + Motor 500g + Other parts 200g = 1kg
Materials for the mechanical part / structure | 3D printed parts
Motors | 1 Stepper motor (400mn.m) we need more or less 100mn.m
Manufacturing equipment | 3D Printer
Assembly between parts | Bolts and nuts
Electronic & programming part
Microcontroller | ESP32
Drivers | TMC2209
Sensors | 1 Ultrasonic sensors + 2 IR Break Beam Sensor
Communication | Wifi
Programming | Arduino IDE

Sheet: Conceptual_Design
CONCEPTUAL DESIGN
Include an image (or more than one) with the current status of the conceptual design. Can be a sketches done with pencil

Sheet: Shopping list
PRELIMINAR ORDER LIST
Team: | BasketBot |  | Total cost [€] | 91.92
 |  |  | Budget limit [€] | 300
Item number | Description of the material | Quantity | Price [€] | Cost [€] | Provider | Link / website
1 | Motor NEMA 17 Stepper Torque=0,4 Nm + 400 mm Integrated Lead Screw | 1 | 32.22 | 32.22 | Amazon | https://www.amazon.es/Iverntech-NEMA-17-integrado-impresora/dp/B07YQQGQ4C
2 | Driver TMC2209 | 1 | 10.32 | 10.32 | Amazon | https://www.amazon.es/TMC2209-Controlador-Motor-Ultra-Silencioso/dp/B0C33GSGN7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
3 | ESP32 | 1 | 6.87 | 6.87 | Amazon | https://www.amazon.es/TECNOIOT-Development-Bluetooth-ESP-32S-Ultra-Low/dp/B07N97DD1B
4 | TSOP4838 | 1 | 11.04 | 11.04 | Adafruit | https://www.amazon.es/Vishay-TSOP4838-TSOP4838-5pcs/dp/B00UO9VO8O
5 | Ultrasonic Sensor | 1 | 5.78 | 5.78 | Amazon | https://www.amazon.es/DollaTek-medici%C3%B3n-Distancia-ultrasonidos-transductor/dp/B07DK55VN7
6 | TM1637 | 2 | 5.6 | 11.2 | Amazon | https://www.amazon.es/visualizaci%C3%B3n-pulgadas-conductor-programable-segmentos/dp/B0D9Q563BD
7 | Push button | 2 | 0.3 | 0.6 | Amazon | https://www.amazon.es/DAOKAI-interruptor-moment%C3%A1neo-componentes-electr%C3%B3nicos/dp/B09WVFHMSV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
8 | Blue Led | 1 | 0.3 | 0.3 | Robotlandia | https://robotlandia.es/luz/1089-diodos-led-de-10-mm-para-arduino-varios-colores.html
9 | Red Led | 1 | 0.3 | 0.3 | Robotlandia | https://robotlandia.es/luz/1090-diodos-led-de-10-mm-para-arduino-varios-colores.html
10 | Green Led | 1 | 0.3 | 0.3 | Robotlandia | https://robotlandia.es/luz/1087-diodos-led-de-10-mm-para-arduino-varios-colores.html
11 | Limit sensor switch | 1 | 1 | 1 | Amazon | https://www.amazon.es/OTOTEC-Microinterruptor-Palanca-Equipos-Electr%C3%B3nicos/dp/B0F9XY54M7
12 | Rsistor 330 Ω | 3 | 1 | 3 | Amazon | https://www.amazon.es/YOKIVE-resistencias-tolerancias-proyectos-electr%C3%B3nicos/dp/B0BNHSLXLK
13 | Protoboard | 1 | 2 | 2 | Amazon | https://www.amazon.es/ELEGOO-Breadboard-Prototipo-Soldaduras-Realizado/dp/B0CY4YGWZ4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
14 | LED IR de 940 nm | 1 | 5.99 | 5.99 | Amazon | https://www.amazon.es/Hailege-Infrared-Receiver-Emission-10Receiver/dp/B07Y2RK1FF
15 | Rsistor 100 Ω | 1 | 1 | 1 | Amazon | https://www.amazon.es/YOKIVE-resistencias-tolerancias-proyectos-electr%C3%B3nicos/dp/B0BMXDTM9T
16
17
18 |  |  |  | 0
19 |  |  |  | 0
20 |  |  |  | 0
21 |  |  |  | 0
22 |  |  |  | 0

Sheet: Recommended suppliers
Provider | Description | link
RS Online | distributor of electronics, electricity and industrial maintenance products | https://es.rs-online.com/
BCN 3D Technologies | 3D Printing Filament distributor for our 3D printer BCN 3D Sigma | https://www.bcn3dtechnologies.com/ca/
Robotshop | Stepper motor, grippers, servo motors, arduinos, raspberry Pi, drivers for motors | https://www.robotshop.com/
Motedis | Mechanical components, aluminium profiles | https://www.motedis.es/shop/index.php
Amazon | Electronics and more | https://www.amazon.es/
ALACER MAS | Mechanical components, aluminium profiles | http://www.alacermas.com/index.php
Please check also the list of recommended providers in the virtual campus.
https://campus.uvic.cat/aules/pluginfile.php/830007/mod_resource/content/2/IP2_List_of_possible_providers.pdf

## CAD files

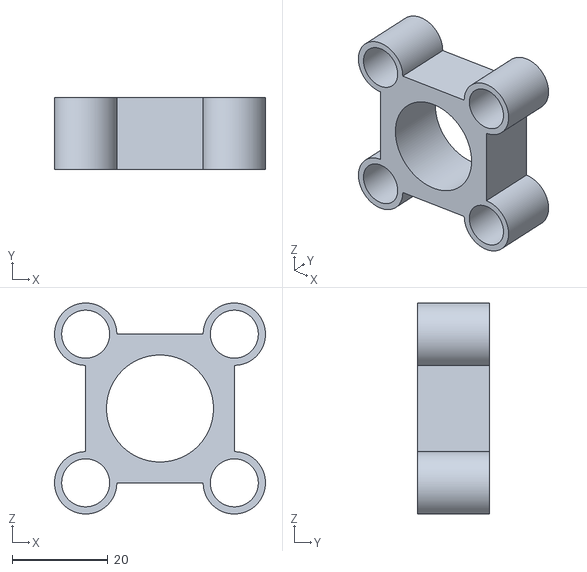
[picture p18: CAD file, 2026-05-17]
Design/transmissio_2.stl
44.0 x 15.0 x 44.0

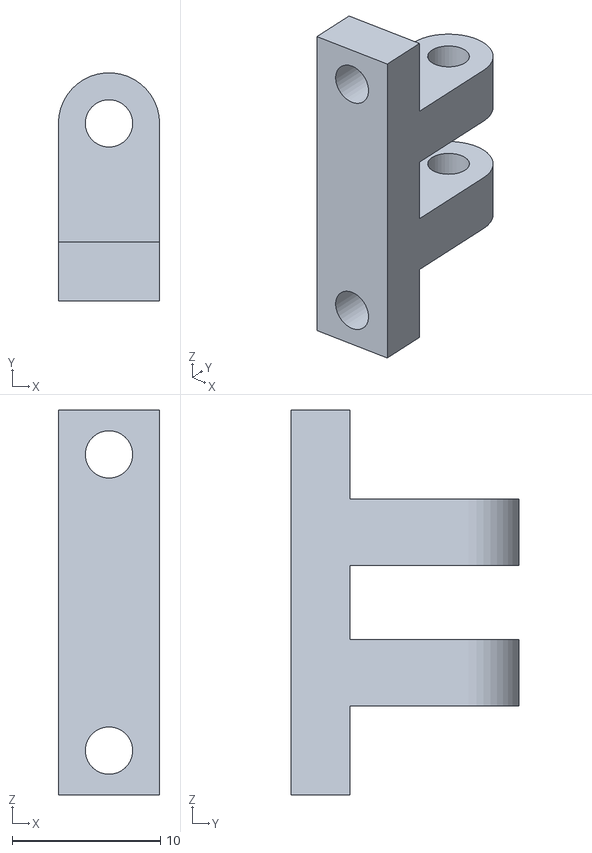
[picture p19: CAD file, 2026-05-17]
Design/enganxe_tablero_cos.stl
6.84 x 15.4 x 26.0

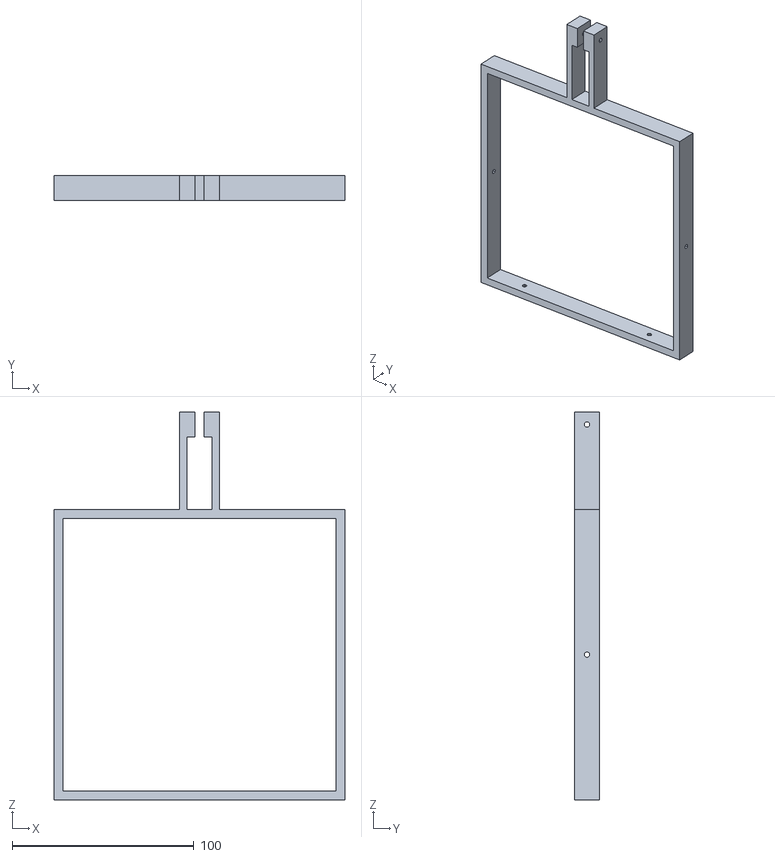
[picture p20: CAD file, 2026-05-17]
Design/suport_canasta_baix_2.stl
160.0 x 13.7 x 213.6

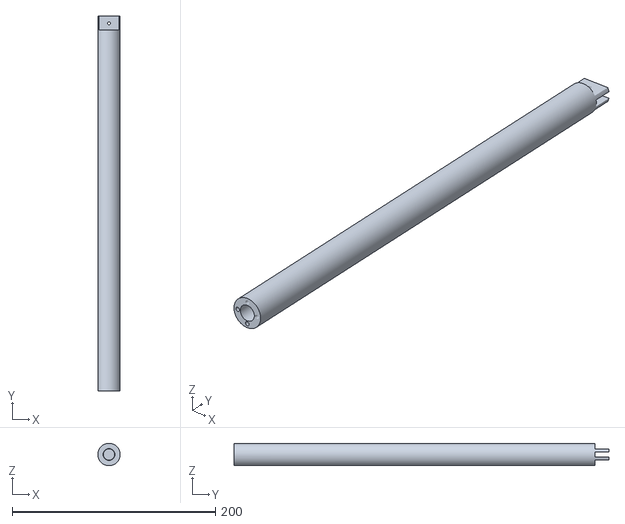
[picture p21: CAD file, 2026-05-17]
Design/transmissio_1.stl
22.0 x 368.7 x 22.0

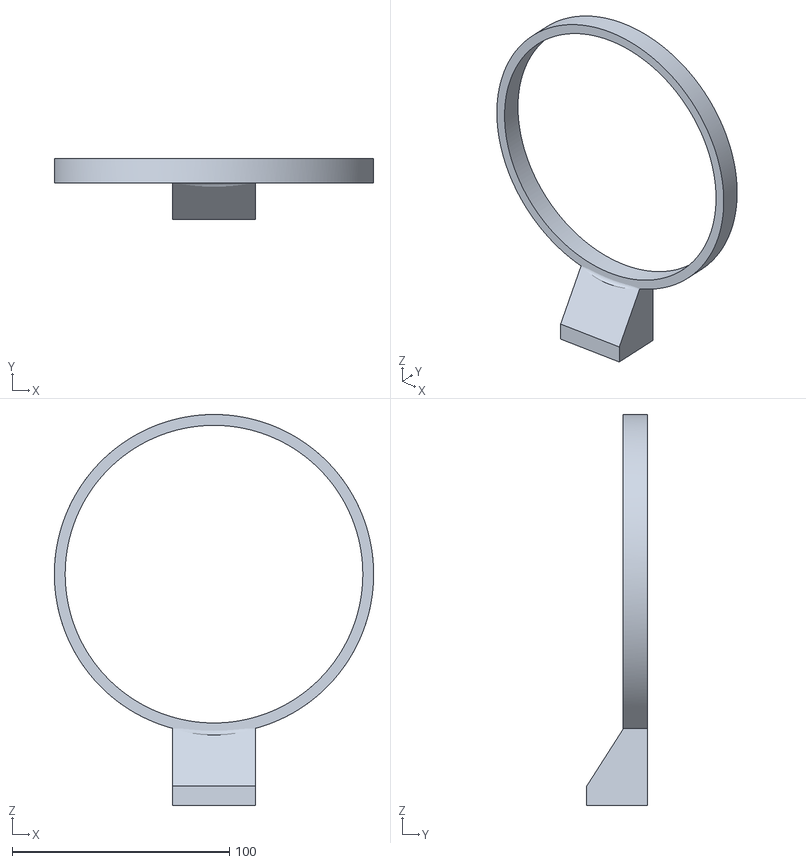
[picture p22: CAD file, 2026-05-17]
Design/aro.stl
147.0 x 28.0 x 180.0

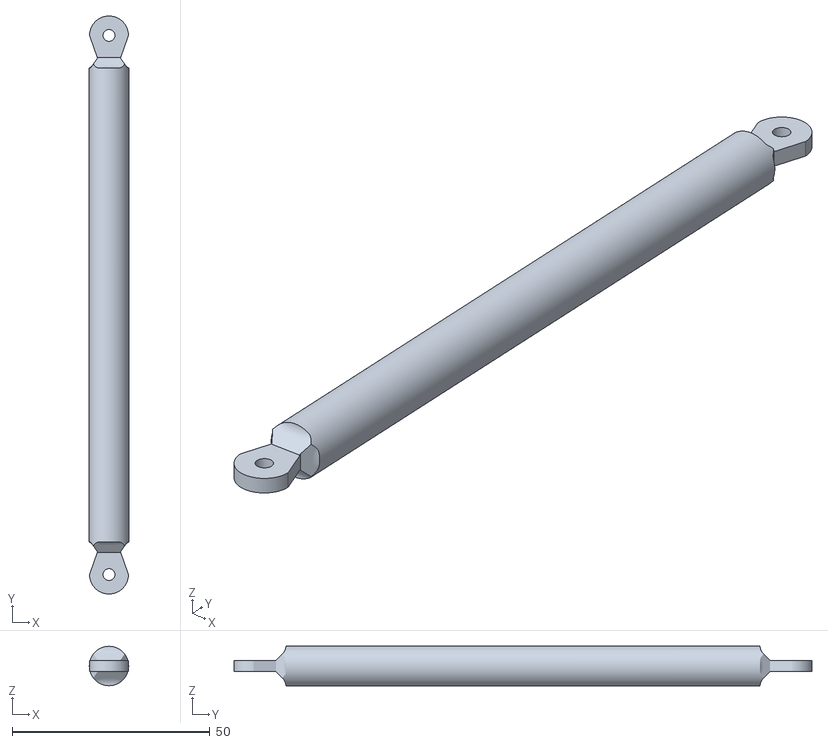
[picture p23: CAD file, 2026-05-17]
Design/pinyo_bo.stl
10.00 x 146.3 x 10.0

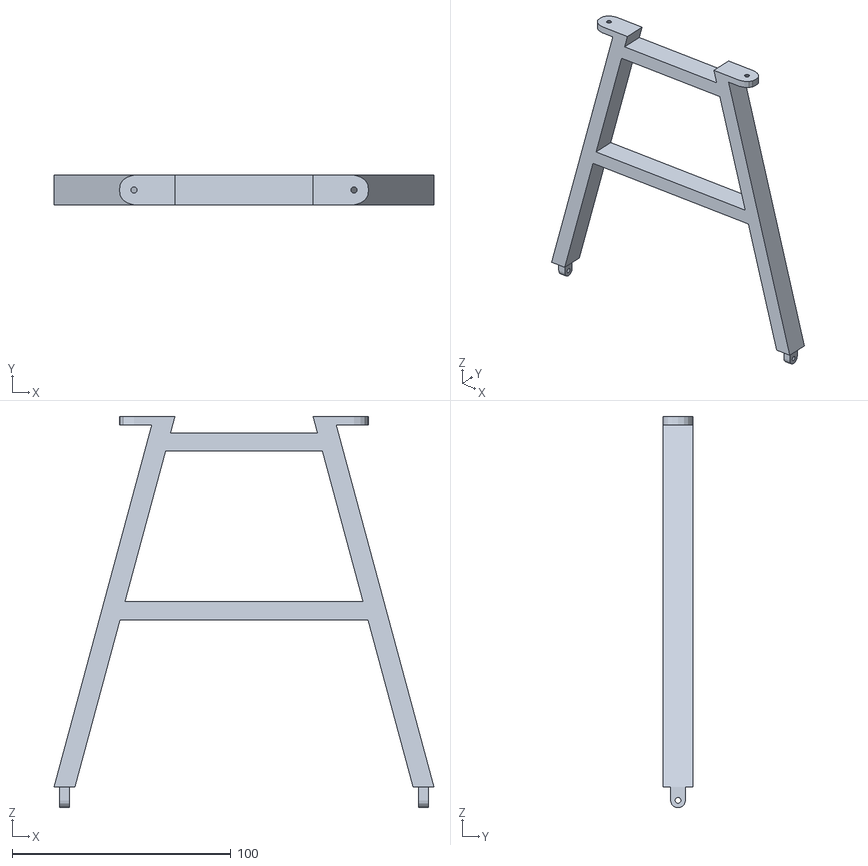
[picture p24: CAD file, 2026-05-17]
Design/suport_canasta_dalt_2.stl
173.7 x 13.7 x 178.9

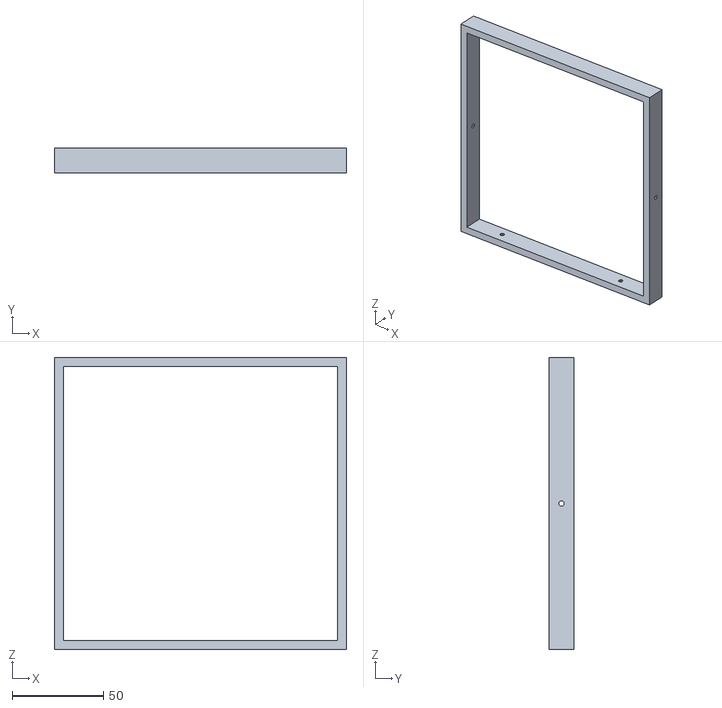
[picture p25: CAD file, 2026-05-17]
Design/suport_canasta_dalt_1.stl
160.0 x 13.7 x 160.0

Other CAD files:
Design/suport_canasta_baix.stl

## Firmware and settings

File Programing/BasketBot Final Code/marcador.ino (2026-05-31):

/*
 * BasketBot — Archivo principal
 *
 * Archivos del proyecto:
 *   marcador.ino         <- este archivo
 *   sensor_canasta.h     <- Detección IR dual (arriba/abajo)
 *   display_timer.h      <- TM1637 tiempo  (CLK 26 / DIO 4)
 *   display_score.h      <- TM1637 puntos  (CLK 14 / DIO 27)
 *   game_1vs1.h          <- partido equipo A vs B por tiempo
 *   game_21.h            <- juego 21 (1-4 jugadores)
 *   game_libre.h         <- marcador libre (+2 / -2)
 *   game_shootout.h      <- shoot out: máximos puntos por turno
 *   motor_canasta.h      <- Control NEMA 17 altura canasta
 *   webpage.h            <- HTML/CSS/JS de la app
 */

#include <WiFi.h>
#include <WebServer.h>
#include "webpage.h"
#include "sensor_canasta.h"  // ← NUEVO: Sistema de detección centralizado
#include "game_1vs1.h"
#include "game_21.h"
#include "game_libre.h"
#include "game_shootout.h"
#include "display_timer.h"   // TM1637 izquierdo — tiempo
#include "display_score.h"   // TM1637 derecho   — puntos
#include "motor_canasta.h"   // NEMA 17 ajuste altura canasta

const char* AP_SSID = "BasketBot";
const char* AP_PASS = "paytowin";

WebServer server(80);

enum ModoJuego { NINGUNO, MODO_1VS1, MODO_21, MODO_LIBRE, MODO_SHOOTOUT };
ModoJuego modoActual = NINGUNO;

// ─── CALLBACK: CANASTA DETECTADA ─────────────────────────────────────────────
/*
 * Esta función se ejecuta automáticamente cuando el sensor detecta una canasta.
 * NO notifica a los modos de juego aquí — eso se hace en loop() para mantener
 * la lógica centralizada y facilitar el debug.
 */
void onCanastaDetectada() {
  Serial.println("[MAIN] 🏀 Canasta física detectada por sensor");
  // Aquí puedes agregar efectos adicionales:
  // - Reproducir sonido
  // - LED de confirmación
  // - Enviar notificación push a la app
}

// ─── HANDLERS HTTP ────────────────────────────────────────────────────────────

void handleRoot() { server.send_P(200, "text/html", INDEX_HTML); }

void handleStart() {
  String mode    = server.arg("mode");
  int    timeSeg = server.arg("time").toInt();
  int    ventana = server.arg("ventana").toInt();
  int    players = server.arg("players").toInt();

  if (mode == "1vs1") {
    modoActual = MODO_1VS1;
    game1vs1_iniciar((unsigned long)timeSeg * 1000UL, (unsigned long)ventana);
    Serial.printf("[START] 1vs1 %ds ventana %dms\n", timeSeg, ventana);

  } else if (mode == "21") {
    modoActual = MODO_21;
    game21_iniciar(constrain(players, 1, 4), (unsigned long)ventana);
    Serial.printf("[START] 21 %djug ventana %dms\n", players, ventana);

  } else if (mode == "libre") {
    modoActual = MODO_LIBRE;
    gameLibre_iniciar();
    Serial.println("[START] Modo libre");

  } else if (mode == "shootout") {
    modoActual = MODO_SHOOTOUT;
    gameShootout_iniciar(constrain(players, 1, 4), (unsigned long)timeSeg * 1000UL);
    Serial.printf("[START] Shootout %djug %ds/turno\n", players, timeSeg);

  } else {
    server.send(400, "text/plain", "Modo desconocido"); return;
  }
  server.send(200, "text/plain", "OK");
}

void handleStatus() {
  String json = "{";
  if      (modoActual == MODO_1VS1)     json += game1vs1_statusJSON();
  else if (modoActual == MODO_21)       json += game21_statusJSON();
  else if (modoActual == MODO_LIBRE)    json += gameLibre_statusJSON();
  else if (modoActual == MODO_SHOOTOUT) json += gameShootout_statusJSON();
  else json += "\"state\":\"Esperando\",\"mode\":\"none\"";
  json += "}";
  server.send(200, "application/json", json);
}

void handlePoint() {
  String action = server.arg("action");
  int    player = server.arg("player").toInt();

  if      (modoActual == MODO_1VS1)                   game1vs1_puntoManual(player);
  else if (modoActual == MODO_21)                     game21_puntoManual(player);
  else if (modoActual == MODO_LIBRE && action=="sub") gameLibre_restar();
  else if (modoActual == MODO_LIBRE)                  gameLibre_sumar();
  else if (modoActual == MODO_SHOOTOUT)               gameShootout_canastaManual();
  server.send(200, "text/plain", "OK");
}

void handleFallo() {
  if (modoActual == MODO_21) game21_falloManual();
  server.send(200, "text/plain", "OK");
}

void handleListo() {
  if (modoActual == MODO_SHOOTOUT) gameShootout_listoManual();
  server.send(200, "text/plain", "OK");
}

void handlePause() {
  bool p = server.arg("state").toInt() == 1;
  if      (modoActual == MODO_1VS1)     game1vs1_setPausa(p);
  else if (modoActual == MODO_21)       game21_setPausa(p);
  else if (modoActual == MODO_LIBRE)    gameLibre_setPausa(p);
  else if (modoActual == MODO_SHOOTOUT) gameShootout_setPausa(p);
  server.send(200, "text/plain", "OK");
}

void handleReset() {
  if      (modoActual == MODO_1VS1)     game1vs1_reset();
  else if (modoActual == MODO_21)       game21_reset();
  else if (modoActual == MODO_LIBRE)    gameLibre_reset();
  else if (modoActual == MODO_SHOOTOUT) gameShootout_reset();
  server.send(200, "text/plain", "OK");
}

// /motor?cm=N  → mover canasta a N cm (0-20), lanza homing si es necesario
void handleMotor() {
  int cm = server.arg("cm").toInt();
  cm = constrain(cm, 0, 20);
  motor_irACm(cm);
  server.send(200, "text/plain", "OK");
}

// /motorstatus → JSON con estado del motor
void handleMotorStatus() {
  String json = "{" + motor_statusJSON() + "}";
  server.send(200, "application/json", json);
}

// /homing → fuerza homing manual desde la app
void handleHoming() {
  motor_homing();
  server.send(200, "text/plain", "OK");
}

// ─── SETUP ───────────────────────────────────────────────────────────────────
void setup() {
  Serial.begin(115200);
  Serial.println("\n=== BasketBot ===");

  // Inicializar sensor de canasta (PRIMERO — es crítico)
  sensor_iniciar();
  sensor_setCallback(onCanastaDetectada);

  // Displays TM1637
  timer_iniciar();   // TM1637 tiempo
  score_iniciar();   // TM1637 puntos

  // Motor NEMA 17 — homing automático al arrancar
  motor_iniciar();
  motor_homing();

  // WiFi Access Point
  WiFi.softAP(AP_SSID, AP_PASS);
  Serial.print("AP IP: "); Serial.println(WiFi.softAPIP());

  // Servidor web
  server.on("/",        HTTP_GET,  handleRoot);
  server.on("/start",   HTTP_POST, handleStart);
  server.on("/status",  HTTP_GET,  handleStatus);
  server.on("/point",   HTTP_POST, handlePoint);
  server.on("/fallo",   HTTP_POST, handleFallo);
  server.on("/listo",   HTTP_POST, handleListo);
  server.on("/pause",   HTTP_POST, handlePause);
  server.on("/reset",   HTTP_POST, handleReset);
  server.on("/motor",       HTTP_POST, handleMotor);
  server.on("/motorstatus", HTTP_GET,  handleMotorStatus);
  server.on("/homing",      HTTP_POST, handleHoming);
  server.begin();

  Serial.println("http://192.168.4.1");
  Serial.println("Cmds: partido,<s>,<ms> | 21,<jug>,<ms> | libre | shootout,<jug>,<s>");
  Serial.println("      listo | stop | reset | status | stats | reset_stats");
}

// ─── LOOP ────────────────────────────────────────────────────────────────────
void loop() {
  server.handleClient();

  // Comandos por serial
  if (Serial.available()) {
    String cmd = Serial.readStringUntil('\n');
    cmd.trim();
    procesarComandoSerial(cmd);
  }

  // ══════════════════════════════════════════════════════════════════════════
  // 1. SENSOR DE CANASTA — máxima prioridad
  // ══════════════════════════════════════════════════════════════════════════
  bool canasta = sensor_tick();

  // Notificar al modo de juego activo si hay canasta
  if (canasta) {
    switch (modoActual) {
      
      case MODO_1VS1:
        game1vs1_notificarCanasta();
        break;
      
      case MODO_21:
        game21_notificarCanasta();
        break;
      
      case MODO_LIBRE:
        gameLibre_notificarCanasta();
        break;
      
      case MODO_SHOOTOUT:
        gameShootout_notificarCanasta();
        break;
      
      default:
        // Sin modo activo, solo loggear
        Serial.println("[MAIN] Canasta detectada pero no hay modo activo");
        break;
    }
  }

  // ══════════════════════════════════════════════════════════════════════════
  // 2. MOTOR — no bloqueante
  // ══════════════════════════════════════════════════════════════════════════
  motor_tick();

  // ══════════════════════════════════════════════════════════════════════════
  // 3. LÓGICA DE JUEGO — procesa timeouts, LEDs, etc.
  // ══════════════════════════════════════════════════════════════════════════
  if      (modoActual == MODO_1VS1)     game1vs1_tick();
  else if (modoActual == MODO_21)       game21_tick();
  else if (modoActual == MODO_LIBRE)    gameLibre_tick();
  else if (modoActual == MODO_SHOOTOUT) gameShootout_tick();

  // ══════════════════════════════════════════════════════════════════════════
  // 4. DISPLAYS TM1637
  // ══════════════════════════════════════════════════════════════════════════
  
  // ── Display Timer: tiempo ─────────────────────────────────────────────────
  unsigned long seg1vs1  = game1vs1_getTiempoRestante() / 1000;
  bool activo1vs1        = game1vs1_estaActivo();
  bool pausado1vs1       = game1vs1_estaPausado();
  bool fin1vs1           = game1vs1_haTerminado();

  unsigned long segSO    = 0;
  bool jugandoSO         = gameShootout_estaJugando();
  bool pausadoSO         = gameShootout_estaPausado();
  bool finSO             = gameShootout_haTerminado();
  if (jugandoSO && !pausadoSO) {
    segSO = gameShootout_getTiempoRestante() / 1000;
  }

  unsigned long segG21   = 0;
  bool actG21            = game21_estaEsperando();
  bool pausG21           = game21_estaPausado();
  bool finG21            = game21_haTerminado();
  if (actG21 && !pausG21) {
    segG21 = game21_getTiempoVentana() / 1000;
  }

  timer_update((int)modoActual,
               seg1vs1,  activo1vs1,  pausado1vs1, fin1vs1,
               segSO,    jugandoSO,   pausadoSO,   finSO,
               segG21,   actG21,      pausG21,     finG21);

  // ── Display Score: puntos ─────────────────────────────────────────────────
  int ptsA, ptsB;
  game1vs1_getPuntos(ptsA, ptsB);
  
  score_update((int)modoActual,
               ptsA, ptsB, activo1vs1, pausado1vs1, fin1vs1,
               gameShootout_getPuntosTurno(), jugandoSO, finSO, pausadoSO,
               game21_getPuntosTurno(), actG21, finG21, pausG21,
               gameLibre_getPuntos(), gameLibre_estaActivo(), gameLibre_estaPausado());
}

// ─── COMANDOS SERIAL ─────────────────────────────────────────────────────────
void procesarComandoSerial(String cmd) {
  // ── Comandos del sensor ──────────────────────────────────────────────────
  if (cmd == "stats") {
    Serial.println("\n=== ESTADÍSTICAS SENSOR ===");
    Serial.print(sensor_getEstadisticas());
    Serial.println("===========================\n");
    return;
  }
  if (cmd == "reset_stats") {
    sensor_resetEstadisticas();
    return;
  }
  if (cmd == "estado_sensor") {
    Serial.println("Estado sensor: " + sensor_getEstado());
    return;
  }
  if (cmd == "reset_sensor") {
    sensor_reset();
    return;
  }

  // ── Comandos de juegos ───────────────────────────────────────────────────
  if (cmd.startsWith("partido")) {
    int c1=cmd.indexOf(','), c2=cmd.indexOf(',',c1+1);
    if (c1!=-1&&c2!=-1) {
      unsigned long s=cmd.substring(c1+1,c2).toInt(), v=cmd.substring(c2+1).toInt();
      if (s>0&&v>0) { modoActual=MODO_1VS1; game1vs1_iniciar(s*1000UL,v); }
      else Serial.println("Params invalidos.");
    } else Serial.println("Formato: partido,<s>,<ms>");
    return;
  }
  if (cmd.startsWith("21")) {
    int c1=cmd.indexOf(','), c2=cmd.indexOf(',',c1+1);
    if (c1!=-1&&c2!=-1) {
      int j=cmd.substring(c1+1,c2).toInt(); unsigned long v=cmd.substring(c2+1).toInt();
      if (j>=1&&j<=4&&v>0) { modoActual=MODO_21; game21_iniciar(j,v); }
      else Serial.println("Jugadores: 1-4");
    } else Serial.println("Formato: 21,<jug>,<ms>");
    return;
  }
  if (cmd.startsWith("shootout")) {
    int c1=cmd.indexOf(','), c2=cmd.indexOf(',',c1+1);
    if (c1!=-1&&c2!=-1) {
      int j=cmd.substring(c1+1,c2).toInt(); unsigned long s=cmd.substring(c2+1).toInt();
      if (j>=1&&j<=4&&s>0) { modoActual=MODO_SHOOTOUT; gameShootout_iniciar(j,s*1000UL); }
      else Serial.println("Jugadores: 1-4, tiempo > 0");
    } else Serial.println("Formato: shootout,<jug>,<seg>");
    return;
  }
  if (cmd=="libre")  { modoActual=MODO_LIBRE; gameLibre_iniciar(); return; }
  if (cmd=="listo" && modoActual==MODO_SHOOTOUT) { gameShootout_listoManual(); return; }
  if (cmd=="stop") {
    if      (modoActual==MODO_1VS1)     game1vs1_stop();
    else if (modoActual==MODO_21)       game21_stop();
    else if (modoActual==MODO_LIBRE)    gameLibre_stop();
    else if (modoActual==MODO_SHOOTOUT) gameShootout_stop();
    return;
  }
  if (cmd=="reset") {
    if      (modoActual==MODO_1VS1)     game1vs1_reset();
    else if (modoActual==MODO_21)       game21_reset();
    else if (modoActual==MODO_LIBRE)    gameLibre_reset();
    else if (modoActual==MODO_SHOOTOUT) gameShootout_reset();
    return;
  }
  if (cmd=="status") {
    if      (modoActual==MODO_1VS1)     game1vs1_printSerial();
    else if (modoActual==MODO_21)       game21_printSerial();
    else if (modoActual==MODO_SHOOTOUT) gameShootout_printSerial();
    else Serial.println("Sin partido activo.");
    return;
  }
  
  Serial.println("\n=== COMANDOS DISPONIBLES ===");
  Serial.println("JUEGOS:");
  Serial.println("  partido,<s>,<ms>      - Iniciar 1vs1");
  Serial.println("  21,<jug>,<ms>         - Iniciar juego 21");
  Serial.println("  shootout,<jug>,<seg>  - Iniciar shootout");
  Serial.println("  libre                 - Iniciar modo libre");
  Serial.println("  listo                 - Jugador listo (shootout)");
  Serial.println("  stop                  - Detener juego");
  Serial.println("  reset                 - Reiniciar juego");
  Serial.println("  status                - Ver estado");
  Serial.println("\nSENSOR:");
  Serial.println("  stats                 - Estadísticas sensor");
  Serial.println("  reset_stats           - Resetear estadísticas");
  Serial.println("  estado_sensor         - Estado actual sensor");
  Serial.println("  reset_sensor          - Reset manual sensor");
  Serial.println("============================\n");
}

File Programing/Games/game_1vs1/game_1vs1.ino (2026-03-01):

// =============================================
//  BasketBot - Partido 1v1 / Equipo vs Equipo
//  Modo simulación: todo se controla por Serial
//
//  Comandos durante el partido:
//    canasta  → simula que el sensor detecta una canasta
//    A        → equipo A confirma (tras canasta detectada)
//    B        → equipo B confirma (tras canasta detectada)
//    stop     → termina el partido manualmente
//
//  Para iniciar:
//    partido,<segundos>,<ventanaPulsadorMs>
//    Ejemplo: partido,120,3000
// =============================================

#define MODO_SIMULACION true  // false para hardware real

#define PIN_SENSOR  2
#define PIN_BTN_A   3
#define PIN_BTN_B   4
#define PIN_LED     13

// =============================================
//  Estado global del partido
// =============================================
bool     partidoActivo    = false;
int      puntos[2]        = {0, 0};
unsigned long tiempoFinMs = 0;
unsigned long ventanaMs   = 0;

// Estados internos
enum EstadoJuego { ESPERANDO_CANASTA, ESPERANDO_PULSADOR };
EstadoJuego estadoActual = ESPERANDO_CANASTA;

unsigned long inicioVentana   = 0;
unsigned long ultimoMarcador  = 0;  // para imprimir el marcador periódicamente

// =============================================
//  Hardware (ignorado en modo simulación)
// =============================================
bool leerSensor() {
  if (MODO_SIMULACION) return false; // en simulación se dispara por Serial
  return digitalRead(PIN_SENSOR) == HIGH;
}

bool leerBotonA() {
  if (MODO_SIMULACION) return false;
  return digitalRead(PIN_BTN_A) == LOW;
}

bool leerBotonB() {
  if (MODO_SIMULACION) return false;
  return digitalRead(PIN_BTN_B) == LOW;
}

void setLED(bool estado) {
  if (!MODO_SIMULACION) digitalWrite(PIN_LED, estado ? HIGH : LOW);
  // En simulación imprimimos el estado del LED
  Serial.print("[LED ");
  Serial.print(estado ? "ON" : "OFF");
  Serial.println("]");
}

// =============================================
//  Imprimir marcador con tiempo restante
// =============================================
void imprimirMarcador() {
  if (!partidoActivo) return;

  unsigned long restanteMs = (millis() < tiempoFinMs) ? (tiempoFinMs - millis()) : 0;
  unsigned int  min = (restanteMs / 1000) / 60;
  unsigned int  s   = (restanteMs / 1000) % 60;

  Serial.println("----------------------------");
  Serial.print("Tiempo restante: ");
  if (min < 10) Serial.print("0");
  Serial.print(min); Serial.print(":");
  if (s < 10) Serial.print("0");
  Serial.println(s);
  Serial.print("  A: "); Serial.print(puntos[0]);
  Serial.print(" pts  |  B: "); Serial.print(puntos[1]);
  Serial.println(" pts");
}

// =============================================
//  Fin del partido
// =============================================
void finPartido() {
  partidoActivo = false;
  setLED(false);

  Serial.println("============================");
  Serial.println("*** TIEMPO AGOTADO ***");
  Serial.print("  Equipo A: "); Serial.print(puntos[0]); Serial.println(" pts");
  Serial.print("  Equipo B: "); Serial.print(puntos[1]); Serial.println(" pts");

  if      (puntos[0] > puntos[1]) Serial.println("*** GANADOR: Equipo A ***");
  else if (puntos[1] > puntos[0]) Serial.println("*** GANADOR: Equipo B ***");
  else                             Serial.println("*** EMPATE ***");

  Serial.println("============================");
  Serial.println("Envía: partido,<segundos>,<ventanaPulsadorMs> para nueva partida.");
}

// =============================================
//  Iniciar partido
// =============================================
void iniciarPartido(unsigned long duracionMs, unsigned long ventanaPulsadorMs) {
  puntos[0]      = 0;
  puntos[1]      = 0;
  tiempoFinMs    = millis() + duracionMs;
  ventanaMs      = ventanaPulsadorMs;
  estadoActual   = ESPERANDO_CANASTA;
  partidoActivo  = true;
  ultimoMarcador = millis();

  Serial.println("=== PARTIDO INICIADO ===");
  Serial.print("Duración: "); Serial.print(duracionMs / 1000); Serial.println(" s");
  Serial.print("Ventana pulsador: "); Serial.print(ventanaMs / 1000); Serial.println(" s");
  Serial.println("Comandos: 'canasta', 'A', 'B', 'stop'");
  Serial.println("========================");
  imprimirMarcador();
  Serial.println("Esperando canasta...");
}

// =============================================
//  Procesar evento de canasta detectada
// =============================================
void canasta_detectada() {
  Serial.println(">> CANASTA detectada! Pulsad A o B para confirmar...");
  setLED(true);
  estadoActual  = ESPERANDO_PULSADOR;
  inicioVentana = millis();
}

// =============================================
//  Procesar pulsador de equipo
// =============================================
void confirmarCanasta(int equipo) {
  const int PUNTOS_CANASTA = 2;
  const char* nombres[2] = {"Equipo A", "Equipo B"};

  setLED(false);
  estadoActual = ESPERANDO_CANASTA;

  puntos[equipo] += PUNTOS_CANASTA;
  Serial.print(">> ");
  Serial.print(nombres[equipo]);
  Serial.print(" anota! +");
  Serial.print(PUNTOS_CANASTA);
  Serial.print(" pts → Total: ");
  Serial.println(puntos[equipo]);

  imprimirMarcador();
  Serial.println("Esperando canasta...");
}

// =============================================
//  Loop principal del partido (no bloqueante)
// =============================================
void tickPartido() {
  if (!partidoActivo) return;

  // ¿Se acabó el tiempo?
  if (millis() >= tiempoFinMs) {
    finPartido();
    return;
  }

  // Imprimir marcador cada 10 segundos
  if (millis() - ultimoMarcador >= 10000) {
    ultimoMarcador = millis();
    imprimirMarcador();
  }

  // Comprobar hardware real (ignorado en simulación)
  if (estadoActual == ESPERANDO_CANASTA) {
    if (leerSensor()) canasta_detectada();

  } else if (estadoActual == ESPERANDO_PULSADOR) {
    // ¿Expiró la ventana?
    if (millis() - inicioVentana >= ventanaMs) {
      setLED(false);
      estadoActual = ESPERANDO_CANASTA;
      Serial.println(">> Tiempo agotado. Canasta anulada.");
      Serial.println("Esperando canasta...");
      return;
    }
    if (leerBotonA()) confirmarCanasta(0);
    if (leerBotonB()) confirmarCanasta(1);
  }
}
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

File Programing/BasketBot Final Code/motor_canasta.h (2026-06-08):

#pragma once

#define MC_STEP_PIN    32
#define MC_DIR_PIN     33
#define MC_EN_PIN      25
#define MC_FC_PIN      35     // ← CAMBIADO de 15 a 35 (evita conflicto con sensor)

#define MC_PASOS_POR_CM   2000L
#define MC_CM_MAX         20
#define MC_PASOS_MAX      ((long)MC_CM_MAX * MC_PASOS_POR_CM)   // 40 000
#define MC_HOMING_BACKUP  300      // pasos hacia arriba tras tocar FC
#define MC_HOMING_LIMITE  50000L   // si no toca FC en este nº de pasos → error
#define MC_VEL_US         800      // microsegundos entre HIGH y LOW del STEP
                                   // (bajar para ir más rápido, mínimo ~300)

// ─── ESTADOS ─────────────────────────────────────────────────────────────────
enum McEstado { MC_IDLE, MC_HOMING_DOWN, MC_HOMING_UP, MC_MOVING, MC_ERROR };

static McEstado  _mc_estado          = MC_IDLE;
static long      _mc_posActual       = 0;     // pasos desde HOME (0 = posición más baja)
static long      _mc_posObjetivo     = 0;
static int       _mc_cmObjetivo      = 0;     // último cm pedido (0-20)
static long      _mc_homingContador  = 0;     // pasos dados durante homing
static int       _mc_homingBackup    = 0;     // pasos dados en la fase de subida
static unsigned long _mc_ultimoPaso  = 0;     // micros del último paso dado

// ─── HELPERS ─────────────────────────────────────────────────────────────────
static void _mc_step() {
  digitalWrite(MC_STEP_PIN, HIGH);
  delayMicroseconds(MC_VEL_US);
  digitalWrite(MC_STEP_PIN, LOW);
  delayMicroseconds(MC_VEL_US);
}

static bool _mc_fcActivo() {
  // FC activo HIGH (INPUT_PULLUP + señal cierra a VCC — revisa tu hardware)
  // Si tu FC cierra a GND cambia a: return digitalRead(MC_FC_PIN) == LOW;
  return digitalRead(MC_FC_PIN) == HIGH;
}

// ─── API PÚBLICA ─────────────────────────────────────────────────────────────

void motor_iniciar() {
  pinMode(MC_STEP_PIN, OUTPUT);
  pinMode(MC_DIR_PIN,  OUTPUT);
  pinMode(MC_EN_PIN,   OUTPUT);
  pinMode(MC_FC_PIN,   INPUT_PULLUP);

  digitalWrite(MC_EN_PIN, LOW);   // motor activo
  Serial.println("[MOTOR] Iniciado (FC en GPIO 35). Lanzando homing...");
}

// Lanza secuencia de homing (no bloqueante, continúa en motor_tick)
void motor_homing() {
  _mc_estado         = MC_HOMING_DOWN;
  _mc_homingContador = 0;
  _mc_homingBackup   = 0;
  _mc_posActual      = 0;
  _mc_posObjetivo    = 0;
  digitalWrite(MC_DIR_PIN, HIGH);   // bajar
  Serial.println("[MOTOR] Homing: bajando hacia FC...");
}

// Envía motor a posición en cm (0-20). Lanza homing si es necesario primero.
void motor_irACm(int cm) {
  cm = constrain(cm, 0, MC_CM_MAX);
  _mc_cmObjetivo  = cm;
  _mc_posObjetivo = (long)cm * MC_PASOS_POR_CM;

  if (_mc_estado == MC_ERROR || _mc_estado == MC_HOMING_DOWN || _mc_estado == MC_HOMING_UP) {
    Serial.printf("[MOTOR] Pendiente ir a %d cm tras homing\n", cm);
    return;   // motor_tick irá allí automáticamente cuando acabe el homing
  }

  if (_mc_posActual == _mc_posObjetivo) {
    Serial.printf("[MOTOR] Ya en %d cm\n", cm);
    return;
  }

  _mc_estado = MC_MOVING;
  if (_mc_posObjetivo > _mc_posActual) {
    digitalWrite(MC_DIR_PIN, LOW);   // subir (alejarse del FC)
    Serial.printf("[MOTOR] Subiendo a %d cm\n", cm);
  } else {
    digitalWrite(MC_DIR_PIN, HIGH);  // bajar (acercarse al FC)
    Serial.printf("[MOTOR] Bajando a %d cm\n", cm);
  }
}

// Estado para la app
bool motor_ocupado()   { return _mc_estado != MC_IDLE && _mc_estado != MC_ERROR; }
bool motor_error()     { return _mc_estado == MC_ERROR; }
int  motor_cmActual()  { return (int)(_mc_posActual / MC_PASOS_POR_CM); }
int  motor_cmObjetivo(){ return _mc_cmObjetivo; }

String motor_statusJSON() {
  String st;
  switch(_mc_estado) {
    case MC_IDLE:         st="Listo";    break;
    case MC_HOMING_DOWN:
    case MC_HOMING_UP:    st="Homing";   break;
    case MC_MOVING:       st="Moviendo"; break;
    case MC_ERROR:        st="Error";    break;
    default:              st="Desconocido";
  }
  String j = "";
  j += "\"motorState\":\"" + st + "\",";
  j += "\"motorCm\":"      + String(motor_cmActual())   + ",";
  j += "\"motorTarget\":"  + String(_mc_cmObjetivo);
  return j;
}

// ─── TICK — llamar en cada loop() ────────────────────────────────────────────
void motor_tick() {
  // ── HOMING: bajando hasta el final de carrera ────────────────────────────
  if (_mc_estado == MC_HOMING_DOWN) {
    if (_mc_fcActivo()) {
      // Tocó el final de carrera → ahora subir 300 pasos
      _mc_homingBackup = 0;
      _mc_estado = MC_HOMING_UP;
      digitalWrite(MC_DIR_PIN, LOW);  // subir
      Serial.println("[MOTOR] FC activado. Subiendo para liberarlo...");
      return;
    }
    if (_mc_homingContador >= MC_HOMING_LIMITE) {
      _mc_estado = MC_ERROR;
      digitalWrite(MC_EN_PIN, HIGH);  // apagar motor
      Serial.println("[MOTOR] ERROR: FC no encontrado. Motor deshabilitado.");
      return;
    }
    _mc_step();
    _mc_homingContador++;
    return;
  }

  // ── HOMING: subiendo para liberar el FC ──────────────────────────────────
  if (_mc_estado == MC_HOMING_UP) {
    if (_mc_homingBackup >= MC_HOMING_BACKUP) {
      // Homing completo → posición HOME = 0
      _mc_posActual   = 0;
      _mc_estado      = MC_IDLE;
      Serial.println("[MOTOR] Homing completado. Posición HOME = 0 cm.");
      // Si había un objetivo pendiente, ir a él
      if (_mc_posObjetivo > 0) {
        motor_irACm(_mc_cmObjetivo);
      }
      return;
    }
    _mc_step();
    _mc_homingBackup++;
    return;
  }

  // ── MOVING: moviéndose hacia objetivo ────────────────────────────────────
  if (_mc_estado == MC_MOVING) {
    if (_mc_posActual == _mc_posObjetivo) {
      _mc_estado = MC_IDLE;
      Serial.printf("[MOTOR] Posición alcanzada: %d cm (%ld pasos)\n",
                    motor_cmActual(), _mc_posActual);
      return;
    }

    // Seguridad: no pasar de los límites
    if (_mc_posObjetivo > _mc_posActual) {
      // Subiendo
      if (_mc_posActual >= MC_PASOS_MAX) {
        _mc_posObjetivo = MC_PASOS_MAX;
        _mc_estado = MC_IDLE;
        return;
      }
      _mc_step();
      _mc_posActual++;
    } else {
      // Bajando — también comprobamos el FC por seguridad
      if (_mc_fcActivo()) {
        _mc_posActual  = 0;
        _mc_posObjetivo = 0;
        _mc_estado = MC_IDLE;
        Serial.println("[MOTOR] FC inesperado durante movimiento. Parado en HOME.");
        return;
      }
      _mc_step();
      _mc_posActual--;
    }
    return;
  }
}

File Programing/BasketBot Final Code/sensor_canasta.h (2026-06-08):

#pragma once

// ─── CONFIGURACIÓN DE HARDWARE ───────────────────────────────────────────────
#define SC_PIN_SENSOR_ARRIBA  15
#define SC_PIN_SENSOR_ABAJO   13
#define SC_PIN_IR_EMISOR      12

// ─── CONFIGURACIÓN IR ────────────────────────────────────────────────────────
#define SC_FRECUENCIA_IR      38000    // Hz - frecuencia del TSOP58438
#define SC_DUTY_CYCLE         127      // 50% duty cycle (0-255)
#define SC_DURACION_RAFAGA_US 2000     // Duración de la ráfaga IR en microsegundos

// ─── TIEMPOS DE DETECCIÓN ────────────────────────────────────────────────────
#define SC_TIEMPO_MAX_CAIDA   600      // ms máximo entre aro y red (trayectoria normal)
#define SC_COOLDOWN_CANASTA   500      // ms de bloqueo tras canasta válida (anti-rebote)
#define SC_DELAY_LECTURA      15       // ms de espera entre lecturas (recuperación sensor)

// ─── ESTADOS ─────────────────────────────────────────────────────────────────
enum ScEstado {
  SC_IDLE,              // Esperando detección inicial
  SC_ESPERANDO_RED,     // Aro detectado, esperando que pase por la red
  SC_COOLDOWN           // Canasta confirmada, en periodo de anti-rebote
};

// ─── VARIABLES PRIVADAS ──────────────────────────────────────────────────────
static ScEstado      _sc_estado          = SC_IDLE;
static unsigned long _sc_tiempoAro       = 0;      // Timestamp cuando se detectó el aro
static unsigned long _sc_inicioCooldown  = 0;      // Timestamp inicio del cooldown
static bool          _sc_inicializado    = false;
static unsigned long _sc_ultimaLectura   = 0;      // Control de timing entre lecturas

// Callback opcional para notificar canasta
static void (*_sc_callback_canasta)() = nullptr;

// Estadísticas (opcional, para debug)
static unsigned int  _sc_canastas_validas = 0;
static unsigned int  _sc_fallos_timeout   = 0;
static unsigned int  _sc_entradas_abajo   = 0;    // Intentos desde abajo (inválidos)

// ─── FUNCIONES PRIVADAS ──────────────────────────────────────────────────────

/*
 * Lee un sensor IR con ráfaga de luz IR
 * Retorna true si hay OBSTÁCULO (haz cortado = HIGH)
 *         false si haz libre (recibe IR = LOW)
 */
static bool _sc_leerSensor(int pin) {
  // Activar emisor IR
  ledcWrite(SC_PIN_IR_EMISOR, SC_DUTY_CYCLE);
  delayMicroseconds(SC_DURACION_RAFAGA_US);
  
  // Leer estado del sensor
  bool obstaculo = (digitalRead(pin) == HIGH);
  
  // Apagar emisor IR
  ledcWrite(SC_PIN_IR_EMISOR, 0);
  
  return obstaculo;
}

/*
 * Registra una canasta válida
 */
static void _sc_registrarCanasta() {
  _sc_canastas_validas++;
  _sc_estado = SC_COOLDOWN;
  _sc_inicioCooldown = millis();
  
  Serial.println("[SENSOR] *** CANASTA VÁLIDA ***");
  
  // Ejecutar callback si está registrado
  if (_sc_callback_canasta != nullptr) {
    _sc_callback_canasta();
  }
}

/*
 * Procesa el timeout de espera de red
 */
static void _sc_procesarTimeout() {
  _sc_fallos_timeout++;
  _sc_estado = SC_IDLE;
  Serial.println("[SENSOR] Fallo: pelota no llegó a la red (rebote en aro)");
}

/*
 * Filtra entrada inválida desde abajo
 */
static void _sc_filtrarEntradaAbajo() {
  _sc_entradas_abajo++;
  Serial.println("[SENSOR] Ignorado: detección desde abajo sin pasar por aro");
}

// ─── API PÚBLICA ─────────────────────────────────────────────────────────────

/*
 * Inicializa el sistema de sensores
 * Debe llamarse en setup()
 */
void sensor_iniciar() {
  pinMode(SC_PIN_SENSOR_ARRIBA, INPUT);
  pinMode(SC_PIN_SENSOR_ABAJO,  INPUT);
  
  // Configurar PWM para el LED IR (ESP32 Arduino 3.x usa ledcAttach)
  #if ESP_ARDUINO_VERSION >= ESP_ARDUINO_VERSION_VAL(3, 0, 0)
    ledcAttach(SC_PIN_IR_EMISOR, SC_FRECUENCIA_IR, 8);
  #else
    ledcSetup(0, SC_FRECUENCIA_IR, 8);
    ledcAttachPin(SC_PIN_IR_EMISOR, 0);
  #endif
  
  ledcWrite(SC_PIN_IR_EMISOR, 0);  // Emisor apagado inicialmente
  
  _sc_estado          = SC_IDLE;
  _sc_tiempoAro       = 0;
  _sc_inicioCooldown  = 0;
  _sc_ultimaLectura   = 0;
  _sc_inicializado    = true;
  
  // Reset estadísticas
  _sc_canastas_validas = 0;
  _sc_fallos_timeout   = 0;
  _sc_entradas_abajo   = 0;
  
  Serial.println("[SENSOR] Sistema de detección de canasta iniciado");
  Serial.printf("[SENSOR] Tiempo máx caída: %d ms | Cooldown: %d ms\n",
                SC_TIEMPO_MAX_CAIDA, SC_COOLDOWN_CANASTA);
}

/*
 * Registra una función callback que se ejecutará cuando se detecte una canasta
 * Ejemplo: sensor_setCallback(miCallbackCanasta);
 */
void sensor_setCallback(void (*callback)()) {
  _sc_callback_canasta = callback;
}
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

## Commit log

2026-03-19 Motor test
2026-03-25 Add designs
    [transmissio_1.stl, transmissio_2.stl]
2026-05-17 Add some files
    [aro.stl, enganxe_tablero_cos.stl, pinyo_bo.stl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]
